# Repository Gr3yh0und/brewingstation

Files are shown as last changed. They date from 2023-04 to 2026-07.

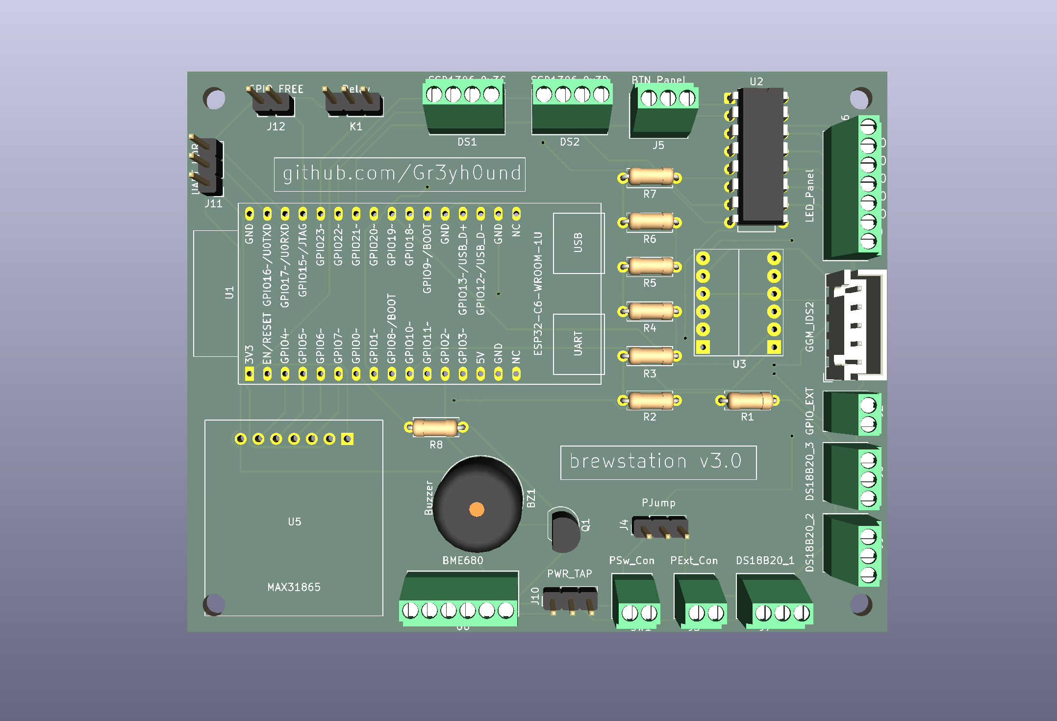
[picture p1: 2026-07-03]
brewingstation3/kicad/brewingstation3.png

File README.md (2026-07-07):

# Brewing Station






Firmware, hardware, and PCB design for a DIY automated beer brewing controller. An ESP32-based device reads mash temperature from multiple sensors, drives a [GGM IDS2 induction cooktop](https://www.ggmgastro.com/de-de-eur/induktionsherd-3-5-kw-1) through PID control, and integrates with [CraftBeerPi](https://web.craftbeerpi.com/) via MQTT.

This repo tracks the project's evolution across several hardware/firmware generations.

Credit: the GGM IDS2 induction cooktop's RS232/serial protocol — pulse timings, command frames, power levels, and error codes — was reverse-engineered by [InnuendoPi](https://github.com/InnuendoPi) in [MQTTDevice2](https://github.com/InnuendoPi/MQTTDevice2). Every generation in this repo builds on that work.

## Own projects (in order of development)

| Folder | Status | Board | Build system | Notes |
|---|---|---|---|---|
| [brewingstation](brewingstation/) | V1 | ESP32 (DOIT ESP32 DEVKIT V1) | Arduino IDE (`.ino`) or PlatformIO | One firmware, two hardware variants: [breadboard](brewingstation/hardware/breadboard/) and [fabricated PCB](brewingstation/hardware/pcb/). Documented in its own [README](brewingstation/README.md). |
| [brewingstation3](brewingstation3/) | **WIP** | ESP32-C6-WROOM-1U | PlatformIO | Full rewrite: PID mash control, multi-sensor support, safety shutdowns, brew timer, KiCad schematic, 3D-printable case. See [README](brewingstation3/README.md), [HARDWARE.md](brewingstation3/HARDWARE.md), [BOM.md](brewingstation3/BOM.md), [CASE.md](brewingstation3/CASE.md). |

`brewingstation` carries a `platformio.ini` (`src_dir = .`) alongside its `.ino`, so both PlatformIO and the Arduino IDE build from the same source file — pick whichever toolchain you prefer.

All generations share the same core idea: control the GGM IDS2 induction cooktop over its proprietary serial protocol, read temperature from DS18B20/PT100/PT1000/BME sensors, drive a couple of OLED displays and status LEDs, and talk to CraftBeerPi over MQTT.

`brewingstation3` is where active development happens; the earlier folders are kept as historical/reference hardware revisions. It is **work in progress**: firmware compiles but is not yet proven on real hardware — the PCB hasn't been soldered/assembled, nothing has been tested end-to-end, and the 3D-printable case hasn't been printed.

## Getting started

Each own-project folder is self-contained with its own README and config. In general:

1. Pick a generation — `brewingstation3` for new builds, the earlier folders for reference or repairing existing hardware.
2. Copy `config_example.h` (or `include/config_example.h` for `brewingstation3`) to `config.h` and fill in your MQTT/OTA settings (`brewingstation3` also provisions WiFi separately, via a WiFiManager captive portal on first boot — see its README). `config.h` is gitignored — never commit real credentials.
3. Build with PlatformIO (`pio run`) or open the `.ino` directly in the Arduino IDE — see that folder's README for board-specific notes.

The whole repo can also be opened as a single VS Code workspace via [brewingstation.code-workspace](brewingstation.code-workspace).

## Testing

`brewingstation3` has a native unit test suite for its hardware-independent logic (calibration math, button-ladder mapping, induction error codes) — runs on the host, no ESP32 toolchain or device required:

```sh
cd brewingstation3
pio test -e native
```

CI runs both the firmware build and this test suite on every push — see the badge above or [.github/workflows/build-brewingstation3.yml](.github/workflows/build-brewingstation3.yml).

## License

[MIT](LICENSE) — see [LICENSE](LICENSE) for the full text.

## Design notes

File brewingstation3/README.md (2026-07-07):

# Brewing Station 3

Automated beer brewing temperature controller. Reads temperature from multiple sensors, controls a GGM IDS2 induction cooker via a proprietary serial protocol, and runs a PID loop to hold a target mash temperature. Integrates with CraftBeerPi 3 and 4 via MQTT.

**Status: work in progress.** Firmware compiles but is not yet proven on real hardware — the PCB hasn't been soldered/assembled, nothing has been tested end-to-end, and the 3D-printable case hasn't been printed.

**Board:** ESP32-C6-WROOM-1U (ESP32-C6-DevKitC-1-N8)  
**Toolchain:** PlatformIO + VS Code (see [platformio.ini](platformio.ini))  
**Schematic:** KiCad 10 — see [kicad/](kicad/)

| Document | Contents |
|---|---|
| [HARDWARE.md](HARDWARE.md) | Sensors, actuators, connectors, pin map, IDS2 protocol, displays |
| [BOM.md](BOM.md) | Full bill of materials with order links |
| [CASE.md](CASE.md) | 3D-printable enclosure — dimensions, assembly, panel layout |

## Releases

Versioned as `3.0.0-alpha.N` (SemVer, pre-1.0 track) while the hardware is unverified — every [release](../../releases) is marked **pre-release** on GitHub until the PCB is built, soldered, and confirmed working end-to-end, at which point it graduates to `3.0.0`. Tags use a plain `3.*` pattern (no `v` prefix) to avoid colliding with `brewingstation` (V1)'s `vX.Y.Z` tags.

Cutting a release: `git tag 3.0.0-alpha.N && git push origin 3.0.0-alpha.N` — this runs the native test suite as a gate, then builds and publishes binaries, a KiCad design snapshot, and the case source to a GitHub Release. See [.github/workflows/release-brewingstation3.yml](../.github/workflows/release-brewingstation3.yml).

---

## Software Features

### Brewing Control
- **PID temperature control** — Proportional on Measurement (P_ON_M) mode. Default tuning: P=45.27, I=0.2371, D=7.2. All parameters adjustable at runtime via MQTT. Setpoint can be configured while PID is off.
- **Induction cooker control** — GGM IDS2 controlled via a proprietary 33-bit pulse-width serial protocol. 6 discrete power levels (P0–P5); intermediate percentages achieved by PWM-cycling between adjacent levels in a 20-second window. Relay stays on for 60 seconds after power-off for fan cooldown.
- **Multi-sensor support** — Up to 5 sensors total: DS18B20 (OneWire, auto-detected), PT100X via MAX31865, BME680. Sensors auto-detected at boot; bad DS18B20 readings (-127°C) are discarded and the previous value retained.
- **Power cap** — Configurable maximum induction output percentage (`INDUCTION_POWER_CAP`, default 100%). Applied to both the PID output path and direct `heater/power` MQTT commands. Adjustable at runtime via `induction/cap` MQTT topic without reflashing.
- **Brew timer** — Countdown timer driven via MQTT (`timer/set`, `timer/control`). Supports start, pause, and reset. Remaining time shown on Display 1 when active. Expiry logged via syslog.
- **Safety shutdowns** — Three automatic cutoffs disable induction power and the PID: (1) sensor staleness: primary sensor has not reported for 30 seconds; (2) thermal runaway: temperature exceeds setpoint by more than 5°C; (3) cooker error codes: E3 overheat, E7 low voltage, or E8 high voltage received from the cooker RX line. All events are logged via syslog at CRIT severity.

### User Interface
- **Dual OLED display** — Display 1: runtime/clock/timer, PID target temperature, PID output %, Wi-Fi/MQTT status icons. Display 2: sensor temperatures, induction power level and percentage, fan indicator, PID active flag.
- **Button control** — 6 panel buttons on a single ADC pin (IO1) via resistor ladder. Each button directly sets the GGM IDS2 induction cooker to a fixed power level (0 / 20 / 40 / 60 / 80 / 100%). Debounced (250 ms). See button mapping table below.
- **Power-level LEDs** — 8 LEDs driven via PCF8574 I2C GPIO expander (address 0x20), active-LOW. The lit LED always reflects the current IDS2 power state: whichever power level is active, the corresponding LED turns on. The LED updates whenever the power level changes — whether set by a button press, MQTT command, or PID output. P6/P7 are spare outputs available for custom use.

### Network & Platform
- **CraftBeerPi 3 & 4** compatible via MQTT.
- **WiFi provisioning via captive portal** — WiFiManager opens an AP automatically on first boot or a failed connect, or can be forced by holding any panel button for ~2s at power-on. No WiFi credentials are stored in `config.h`. The same portal also lets you set the MQTT broker address, MQTT topic prefix, and OTA password without reflashing.
- **OTA firmware updates** — ArduinoOTA on port 8266, or via the web dashboard's upload form (`http://<ip>/update`); both password-protected (`OTA_PASSWORD` in `config.h`, changeable later via the WiFiManager portal).
- **Web dashboard** — three tabbed pages at `http://<ip>/`, with the hostname and running firmware version shown in the nav bar: **Status** (sensors, setpoint, PID/mode, induction power, relay/GPIO5, brew timer, WiFi signal, uptime, version — auto-refreshes every 5s, no login), **Update** (browser firmware upload, a link to the GitHub releases page, and a "Check for update" button that compares the running version against GitHub directly from the browser), and **Config** (current MQTT/WiFi/PID settings, with a JSON download for backup). Update and Config require the OTA password (HTTP Basic Auth).
- **mDNS** — Device advertises as `ESP-BREWING.local`.
- **Syslog** — UDP logging to backend server on port 514.
- **NTP time sync** — `configTzTime()` called after WiFi connects; POSIX timezone string configurable via `NTP_TIMEZONE` in `config.h`. When synced, Display 1 shows wall-clock time instead of uptime.
- **Hardware watchdog** — ESP32 task watchdog timer (`WDT_TIMEOUT_S`, default 30 s). Reboots the device if `loop()` stalls for any reason.

### Button Mapping

Each button sets the GGM IDS2 induction cooker to a fixed power level. The matching power-level LED lights up immediately after the button is pressed. See [HARDWARE.md](HARDWARE.md#button--led-panel-external--not-on-pcb) for wiring details.

| Button | Panel ref | ADC range | IDS2 power | LED |
|---|---|---|---|---|
| B1 | SW2 | 3200–3299 | 0% (off) | LD1 (LED_0) |
| B2 | SW3 | 3000–3199 | 20% | LD2 (LED_20) |
| B3 | SW4 | 2600–2999 | 40% | LD3 (LED_40) |
| B4 | SW5 | 2000–2599 | 60% | LD4 (LED_60) |
| B5 | SW6 | 1–1999 | 80% | LD5 (LED_80) |
| B6 | SW7 | 0 (ADC_BTN shorted to GND) | 100% | LD6 (LED_100) |

> The LEDs also update when the power level is changed via MQTT or PID output — the lit LED always reflects the **current** IDS2 state, not just the last button pressed.

---

## MQTT

All topics are built from `MQTT_ROOT_PATH / MQTT_DEVICE` — set in `config.h` as first-boot defaults, changeable afterward via the WiFiManager portal (persisted to `/netconfig.json`).

| Topic | Direction | Payload fields |
|---|---|---|
| `.../sensor/N` | publish | `temp` (°C), `ts` |
| `.../induction` | publish | `relay`, `active`, `power`, `level`, `error`, `cap`, `ts` |
| `.../induction/set` | subscribe | `power` (0–100); `state "off"` cuts power |
| `.../induction/cap` | subscribe | `cap` (0–100) — runtime power ceiling |
| `.../pid` | publish | `enabled`, `mode`, `setpoint`, `input`, `output`, `diff`, `P`, `I`, `D`, `ts` |
| `.../pid/enable` | subscribe | `enabled` (bool) |
| `.../pid/reset` | subscribe | _(any payload)_ — resets PID output to 0 |
| `.../pid/p` | subscribe | `P` (float) |
| `.../pid/i` | subscribe | `I` (float) |
| `.../pid/d` | subscribe | `D` (float) |
| `.../pid/setpoint` | subscribe | `setpoint` (float, 0–100°C) |
| `.../timer` | publish | `running`, `paused`, `remaining` (s), `duration` (s), `ts` |
| `.../timer/set` | subscribe | `duration` (seconds) |
| `.../timer/ctl` | subscribe | `cmd`: `"start"` / `"pause"` / `"reset"` |
| `.../device` | publish | `uptime`, `heap`, `rssi`, `version`, `mode`, `ts` |
| `.../device/mode` | subscribe | `mode`: `"standalone"` / `"slave"` |
| `.../relay` | publish | `state`, `remaining`, `ts` |
| `.../relay/set` | subscribe | `state`: `"on"` / `"off"`; optional `duration` (s) |
| `.../gpio_ext` | publish | `state`, `remaining`, `ts` |
| `.../gpio_ext/set` | subscribe | `state`: `"on"` / `"off"`; optional `duration` (s) |

---

## Configuration

Copy `include/config_example.h` to `include/config.h` and fill in your values. `config.h` is gitignored.

```cpp
#define HOSTNAME        "ESP-BREWING"
#define SERVER_ADDRESS  "192.168.0.x"   // Raspberry Pi IP
#define MQTT_ROOT_PATH  "home"
#define MQTT_DEVICE     "brewery"
```

**WiFi credentials are not set in `config.h`.** On first boot (or whenever no saved WiFi credentials connect), the device opens a WiFiManager captive-portal AP — connect to it from a phone/laptop and submit your WiFi SSID/password, MQTT broker address, MQTT topic prefix, and OTA password through its web form. These are stored in the ESP32's NVS (WiFi) and `/netconfig.json` (the rest), surviving reboots and reflashes. To reprovision later without clearing flash, hold any panel button for ~2s at power-on to force the portal open again.

**PT100X vs PT1000:** Default is PT1000 (`R_NOM=1000`, `R_REF=4300`). Change both to `100` / `430` for PT100.

**PID tuning:** Default values (`P=45.27`, `I=0.2371`, `D=7.2`) are tuned for a specific vessel. Adjust `PID_DEFAULT_P/I/D` in `config.h`. Values can also be changed at runtime via MQTT.

**Button ADC thresholds:** `BUTTON_THRESHOLD_B1–B5` depend on actual resistor values. Measure with serial monitor and adjust if buttons trigger at the wrong levels.

**Safety thresholds:** `PID_SAFETY_OVERSHOOT` (default 5°C) and `SENSOR_STALE_TIMEOUT_MS` (default 30s).

**Power cap:** `INDUCTION_POWER_CAP` (default 100%). Override at runtime via `induction/cap` MQTT.

**Watchdog:** `WDT_TIMEOUT_S` (default 30 s).

**NTP:** `NTP_SERVER` (default `pool.ntp.org`) and `NTP_TIMEZONE` (POSIX string). See [nayarsystems/posix_tz_db](https://github.com/nayarsystems/posix_tz_db).

---

## Build & Flash (PlatformIO)

```sh
# Build
pio run -e esp32c6

# Upload via USB-CDC (no external USB-UART chip needed)
pio run -e esp32c6 -t upload

# Serial monitor
pio device monitor

# Debug build (verbose ESP-IDF logs)
pio run -e esp32c6_debug
```

Or use the PlatformIO sidebar in VS Code (Build ✓ / Upload → / Monitor icons).

---

## Libraries

All dependencies are managed by PlatformIO via `platformio.ini`.

| Library | Author | Constraint | Installed |
|---|---|---|---|
| PubSubClient | Nick O'Leary | `^2.8` | 2.8 |
| ArduinoJson | Benoit Blanchon | `^7.0` | 7.4.3 |
| Syslog | Martin Sloup (arcao) | `^2.0` | 2.0.0 |
| Arduino-PID-Library | Brett Beauregard | `^1.2` | 1.2.1 |
| OneWire | Paul Stoffregen | local `lib/` | 2.3.8 (patched) |
| DallasTemperature | Miles Burton | `^3.9` | 3.11.0 |
| Adafruit Unified Sensor | Adafruit | `^1.1` | 1.1.15 |
| Adafruit MAX31865 | Adafruit | `^1.1` | 1.6.2 |
| Adafruit BME680 | Adafruit | `^2.2` | 2.3.0 |
| Adafruit GFX | Adafruit | `^1.11` | 1.12.6 |
| Adafruit SSD1306 | Adafruit | `^2.5` | 2.5.16 |
| PCF8574 | Rob Tillaart | `^0.3` | 0.3.9 |
| arduino-timer | contrem | unpinned | 3.0.1 |

**OneWire note:** Kept as a local copy in `lib/OneWire/` because the upstream release does not handle the ESP32-C6 GPIO register struct (typed fields requiring `.val` in arduino-esp32 3.x). The patch adds `|| CONFIG_IDF_TARGET_ESP32C6` to each `#if CONFIG_IDF_TARGET_ESP32C3` guard in `util/OneWire_direct_gpio.h`.

**Platform:** pioarduino community fork (`pioarduino/platform-espressif32 @ stable`). The official `espressif32` platform references a RISC-V toolchain package (`toolchain-riscv32-esp @ 13.2.0+20240530`) that was removed from the PlatformIO registry; the pioarduino fork bundles the toolchain directly. Bundles arduino-esp32 3.x, which is required for ESP32-C6 support.

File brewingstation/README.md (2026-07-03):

# Brewing Station (V1)

Automated beer brewing temperature controller. Reads temperature from multiple sensors, controls a GGM IDS2 induction cooker via a proprietary serial protocol, and runs a PID loop to hold a target mash temperature. Integrates with CraftBeerPi 3 and 4 via MQTT.

The idea: a "remote hands" station for CraftBeerPi with a local interface, so it also works standalone without a Pi — e.g. for manual-temperature-control outdoor cooking.

**MCU:** ESP32 (DOIT ESP32 DEVKIT V1)
**Toolchain:** Arduino IDE or PlatformIO (see [platformio.ini](platformio.ini))
**Hardware variants:** one firmware, two builds — [breadboard prototype](hardware/breadboard/) and a [fabricated 2-layer PCB](hardware/pcb/) (see [Hardware Variants](#hardware-variants) below)
**Successor:** [brewingstation3](../brewingstation3) — full rewrite on ESP32-C6 with safety shutdowns, brew timer, and a printable case

---

## Induction Cooker

Within this project the [GGM Gastro IDS2 induction cooker](https://www.ggmgastro.com/de-de-eur/induktionsherd-3-5-kw-1) is used to heat the mash tun. It has an external control panel connected via a serial line — reverse-engineered by [InnuendoPi](https://github.com/InnuendoPi) in [MQTTDevice2](https://github.com/InnuendoPi/MQTTDevice2), which this project builds on.

Tested with both CraftBeerPi 3 and 4 — the MQTT API is identical between the two.

---

## Hardware

| Component | Interface | Purpose |
|---|---|---|
| DS18B20 (×2–3) | OneWire | Mash temperature — breadboard build uses 2, PCB build's schematic shows 3 |
| MAX31865 (PT1000) | Software SPI | High-accuracy RTD temperature |
| BME280 | Software SPI | Ambient temperature / humidity / pressure |
| GGM IDS2 induction cooker | 3-wire serial | Heat source |
| 2× SSD1306 OLED 128×64 | I2C, different addresses | Temperature + status display |
| Buttons + LEDs | GPIO | Manual power control (aluminium switches with integrated LEDs) |

The firmware detects sensors at runtime and adapts — the same sketch runs unmodified on either hardware variant, as long as `config.h` pin assignments match the board you're using.

---

## Hardware Variants

Both variants run the exact same firmware (`brewingstation.ino`) — the only difference is the physical build.

| Aspect | Breadboard | PCB |
|---|---|---|
| Form factor | Breadboard prototype | Custom fabricated 2-layer PCB |
| Level shifter | Not shown | Present (3.3V ↔ 5V) |
| DS18B20 count | 2 (config default) | 3 (shown in schematic) |
| Expansion connectors | None | PPump, PJump, PExt, GPIOs |
| Design files | [hardware/breadboard/](hardware/breadboard/) | [hardware/pcb/](hardware/pcb/) |

### Breadboard design files

| File | Description |
|---|---|
| `brewingstation.fzz` | Fritzing project |
| `brewingstation_breadboard.png` | Breadboard wiring view |
| `brewingstation_schematics.png` | Schematic / circuit diagram |
| `brewingstation_pcb.png` | PCB layout (Fritzing-generated) |
| `gerber_pcb.zip` | Gerber files for PCB fabrication |

### PCB design files

| File | Description |
|---|---|
| `brewingstation2.fzz` | Fritzing project (original) |
| `brewingstation2_updated.fzz` | Fritzing project (revised PCB layout) |
| `brewingstation2_Steckplatine.png` | Breadboard wiring view |
| `brewingstation2_Schaltplan.png` | Schematic / circuit diagram |
| `brewingstation2_Leiterplatte.png` | PCB layout (2-layer, "BREWSTATION" silkscreen) |
| `gerber.zip` | Gerber files for PCB fabrication |

The `_updated.fzz` reflects at least one PCB revision after initial design — use the gerbers from the latest revision for fabrication.

### Notable: Level Shifter (PCB variant)

The PCB schematic includes a logic level converter (3.3V ↔ 5V), bridging the ESP32's 3.3V GPIO levels to the 5V signalling required by the induction cooker serial line and/or relay module.

---

## MQTT

Topics are built from `MQTT_ROOT_PATH / MQTT_DEVICE` (set in `config.h`).

| Topic | Direction | Payload fields |
|---|---|---|
| `.../temperature/N` | publish | `temperature` (°C) |
| `.../heater` | publish | `relayOn`, `inductionOn`, `powerPercent`, `powerLevel` |
| `.../heater/power` | subscribe | `state` (`"off"` or unset), `power` (0–100) |
| `.../pid` | publish | `state`, `P`, `I`, `D`, `input`, `targetTemperature`, `tempDiff`, `output` |
| `.../pid/#` | subscribe | PID tuning/setpoint commands |

---

## Configuration

Copy `config_example.h` to `config.h` and fill in your network credentials and server address. `config.h` is gitignored — never commit real credentials.

```cpp
#define HOSTNAME        "ESP-BREWING"
#define SSID_NAME       "your-ssid"
#define SSID_PASSWORD   "your-password"
#define SERVER_ADDRESS  "192.168.0.x"
#define MQTT_ROOT_PATH  "root"
#define MQTT_DEVICE     "brewery"
```

---

## Build & Flash

**PlatformIO:**

```sh
pio run -e esp32doit-devkit-v1
pio run -e esp32doit-devkit-v1 -t upload
pio device monitor
```

**Arduino IDE:** open `brewingstation.ino` directly and install the libraries listed at the top of the sketch.

---

## Known Gaps

This is the earliest surviving generation of the project — some functionality is missing or incomplete:

- PID integration (present in code, not fully tuned/validated)
- Sensor handling (no runtime detection/calibration — see [brewingstation3](../brewingstation3) for that)
- Humidity and pressure MQTT topics (BME280 reads them, but only temperature is published)
- Brew timers / mash-step display (also needs CraftBeerPi-side adaptations)

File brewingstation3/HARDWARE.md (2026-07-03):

# Brewing Station 3 — Hardware Reference

**MCU:** ESP32-C6-WROOM-1U on ESP32-C6-DevKitC-1-N8  
RISC-V single-core 160 MHz, WiFi 6, BLE 5.3, 3.3V I/O, USB-CDC built-in.

---

## Sensors

| Sensor | Interface | Purpose |
|---|---|---|
| DS18B20 (×3) | OneWire (IO11) | Mash temperature — sensor 0 is the PID input |
| MAX31865 / PT100X | Software SPI (CS: IO4) | High-accuracy RTD temperature |
| BME680 | Software SPI (CS: IO2) | Ambient temperature / humidity / pressure |

MAX31865 and BME680 share the same MOSI/MISO/CLK bus (IO7/IO6/IO5) with separate CS pins.

---

## Actuators & UI

| Component | Interface | Purpose |
|---|---|---|
| GGM IDS2 induction cooker | 3-wire serial via BSS138 level shifter (IO18/IO19/IO20) | Heat source |
| Relay module (K1) | IO21 (direct 3.3V, no level shifter) | General-purpose relay (pump / Rührwerk) — external module via 3-pin Dupont header |
| Magnetic buzzer SUMMER CPM 121 (BZ1) | IO0 → BC547B NPN → buzzer → +3V3 | Audible alerts (step complete, safety events) |
| PCF8574 I2C GPIO expander | I2C 0x20 (IO23/IO22) | Drives 8 power-level LEDs (active-LOW) |
| 6× LEDs (LD1–LD6) via P0–P5 | PCF8574 + R2–R7 (330Ω) → J15–J20 (pin 3) | IDS2 power state indicator — lit LED = current power level (0/20/40/60/80/100%) |
| 2× spare LEDs (LD7–LD8) via P6–P7 | PCF8574 + R15–R16 (330Ω) → J21, J22 (pin 2) | Spare outputs for custom use |
| 6× buttons (SW2–SW7) | Resistor ladder (IO1 / ADC1) → J15–J20 (pin 2) | Sets IDS2 cooker power level directly (0/20/40/60/80/100%) |
| 2× SSD1306 OLED 128×64 | I2C 0x3C / 0x3D (IO23/IO22) | Temperature + status display |

---

## Level Shifter

BSS138 4-channel bidirectional level shifter module (VCCA=3.3V, VCCB=5V) bridges the ESP32-C6's 3.3V GPIO to the 5V signalling required by the induction cooker (WHITE/YELLOW/BLUE) on CH2–CH4. CH1 is not connected (IO10 is broken out directly via J13). The relay module is driven directly at 3.3V — select a relay module with 3.3V-compatible opto-coupler input.

---

## Power Chain

IDS2 VCC tap or PExt → PJump (source select) → PSw (on/off) → +5V rail → DevKit VIN + relay module + BSS138 VCCB

---

## PCB Connectors

**Female sockets (2.54mm) — module plugs in:**

| Ref | Component | Socket |
|---|---|---|
| U1 | ESP32-C6-DevKitC-1 | 2× 1×16 female socket strip — DevKit is swappable |
| U3 | BSS138 level shifter module | 2×6 female, 2.54mm |
| U5 | MAX31865 module | 1×7 female, 2.54mm |

**External module connector (Dupont cables):**

| Ref | Component | Connector |
|---|---|---|
| K1 | Relay module | 1×3 male header, 2.54mm (VCC / GND / IN) — relay load contacts on module's own screw terminals |

**Male headers (2.54mm) — jumper cap or dupont wires plug in:**

| Ref | Purpose | Pins |
|---|---|---|
| J4 | PSource — power source selector | 3 (IDS2 tap / PSOURCE_OUT / PExt); short 1-2 or 2-3 |
| J10 | PWR_TAP — voltage reference | 3 (GND, +3V3, +5V) |
| J11 | UART — IO16 TX / IO17 RX | 3 (GND, TX, RX) |

**Phoenix screw terminal GPIO breakouts:**

| Ref | Purpose | Pins |
|---|---|---|
| J12 | GPIO15 breakout | 2 (GND, GPIO15) |
| J13 | GPIO10 breakout | 2 (GND, GPIO10) |
| J14 | GPIO3_ADC breakout | 2 (GND, GPIO3_ADC) |

**IDS2 connector (internal):**

| Ref | Purpose | Type |
|---|---|---|
| J1 | GGM IDS2 induction cooker | Phoenix MPT 5-pin, 2.54mm — IDS2 cable feeds through case wall, individual wires screwed in (IDS2_5V / GND / WHITE / YELLOW / BLUE) |

---

## External Wiring — Screw Terminal Connectors

All screw terminal connections use **Phoenix Contact MPT 0,5/X-2,54** PCB terminal blocks (2.54mm pitch, screw clamp, 6A / 160V, green).  
Reichelt article numbers: [**PHC 1725656**](https://www.reichelt.de/de/de/shop/produkt/leiterplattenklemme_2-polig_rm_2_54-60874) (2-pin), [**PHC 1725669**](https://www.reichelt.de/de/de/shop/produkt/leiterplattenklemme_3-polig_rm_2_54_mm-60875) (3-pin), [**PHC 1725672**](https://www.reichelt.de/de/de/shop/produkt/leiterplattenklemme_4-polig_rm_2_54_mm-60876) (4-pin), [**PHC 1725685**](https://www.reichelt.de/de/de/shop/produkt/leiterplattenklemme_5-polig_rm_2_54_mm-255909) (5-pin).

| Ref | Connector | Pins | Wires to |
|---|---|---|---|
| J3 | External 5V power input (PExt) | 2 (+5V, GND) | Power supply / USB charger |
| SW1 | Main power switch + integrated LED | 4 (SW_A, SW_B, LED+, LED−) | Panel-mounted metal switch; LED driven via R17 (470Ω) from PSOURCE_OUT — always on when power is present |
| J15–J20 | Button + LED per power level (0/20/40/60/80/100%) | 3 (GND, BTN, LED) | J15=0%, J16=20%, J17=40%, J18=60%, J19=80%, J20=100% — each carries one panel button (SW2–SW7) and its matching LED (LD1–LD6) |
| J21, J22 | Spare LEDs (LED_P6, LED_P7) | 2 (GND, LED) | PCF8574 P6/P7 spare outputs |
| J7 | DS18B20 sensor 1 | 3 (GND, +3V3, DQ) | Wire to case-mounted connector → probe |
| J8 | DS18B20 sensor 2 | 3 (GND, +3V3, DQ) | Wire to case-mounted connector → probe |
| J9 | DS18B20 sensor 3 | 3 (GND, +3V3, DQ) | Wire to case-mounted connector → probe |
| U5 | PT1000/PT100 probe (MAX31865) | 4 (FORCE+, FORCE−, RTDIN+, RTDIN−) | Internal cable → case connector → RTD probe |
| U6 | BME680 module | 6 (VCC, GND, SCK, SDI, SDO, CSB) | Module wired directly into terminal |
| DS1 | SSD1306 OLED 0x3C | 4 (GND, VCC, SCL, SDA) | OLED module wired directly into terminal |
| DS2 | SSD1306 OLED 0x3D | 4 (GND, VCC, SCL, SDA) | OLED module wired directly into terminal |
| J12 | GPIO15 breakout | 2 (GND, GPIO15) | Spare GPIO, ADC-capable |
| J13 | GPIO10 breakout | 2 (GND, GPIO10) | Spare GPIO, ADC-capable |
| J14 | GPIO3_ADC breakout | 2 (GND, GPIO3_ADC) | Spare ADC input (ADC1_CH3) |

---

## Pin Map

DevKit pad numbers from the `PCM_Espressif:ESP32-C6-DevKitC-1` footprint.  
IO8/IO9 are strapping pins (DevKit BOOT button) — do not drive as outputs.  
IO12/IO13 are USB D−/D+ — occupied by USB-CDC, not available.  
IO14 is not exposed on the DevKitC-1 headers.  
IO16/IO17 are UART0 TX/RX — free because USB-CDC replaces the hardware UART for `Serial`.

| GPIO | DevKit pad | Signal | Status | Notes |
|---|---|---|---|---|
| IO0 | 7 | Buzzer (BUZZER_PIN) | **Used** | PWM via LEDC → BC547B NPN (Q1) → BZ1 piezo |
| IO1 | 8 | Button ladder (ADC_BTN) | **Used** | ADC1_CH1; 6-button resistor ladder |
| IO2 | 12 | BME680 SPI CS | **Used** | Software SPI chip-select |
| IO3 | 13 | GPIO3_ADC (J14) | **Broken out** | ADC1_CH3; 2-pin Phoenix screw terminal (GND + GPIO3_ADC) |
| IO4 | 3 | MAX31865 SPI CS | **Used** | Software SPI chip-select |
| IO5 | 4 | SPI CLK | **Used** | Shared bus: MAX31865 + BME680 |
| IO6 | 5 | SPI MISO (DO) | **Used** | Shared bus: MAX31865 + BME680 |
| IO7 | 6 | SPI MOSI (DI) | **Used** | Shared bus: MAX31865 + BME680 |
| IO8 | 9 | — | **Restricted** | BOOT strapping pin — do not drive as output |
| IO9 | 22 | — | **Restricted** | BOOT strapping pin — do not drive as output |
| IO10 | 10 | GPIO10 (J13) | **Broken out** | ADC1_CH2; 2-pin Phoenix screw terminal (GND + GPIO10); BSS138 CH1 nc |
| IO11 | 11 | DS18B20 OneWire bus (SENSOR_BUS_PIN) | **Used** | 4.7kΩ pull-up to 3V3 on PCB |
| IO12 | 19 | — | **Restricted** | USB D− — occupied by USB-CDC |
| IO13 | 20 | — | **Restricted** | USB D+ — occupied by USB-CDC |
| IO14 | — | — | **Not exposed** | Not on DevKitC-1 headers |
| IO15 | 29 | GPIO15 (J12) | **Broken out** | 2-pin Phoenix screw terminal (GND + GPIO15) |
| IO16 | 31 | UART_HDR TX | **Free** | UART0 TX; broken out on J11; usable as GPIO when using USB-CDC |
| IO17 | 30 | UART_HDR RX | **Free** | UART0 RX; broken out on J11; usable as GPIO when using USB-CDC |
| IO18 | 23 | Induction WHITE (relay enable) | **Used** | via BSS138 level shifter |
| IO19 | 24 | Induction YELLOW (TX) | **Used** | via BSS138 level shifter |
| IO20 | 25 | Induction BLUE (RX interrupt) | **Used** | via BSS138 level shifter |
| IO21 | 26 | Relay module control (RELAY_PIN) | **Used** | direct 3.3V to K1 Dupont header |
| IO22 | 27 | I2C SCL | **Used** | Displays (0x3C, 0x3D) + PCF8574 (0x20) |
| IO23 | 28 | I2C SDA | **Used** | Displays (0x3C, 0x3D) + PCF8574 (0x20) |

**Summary: 14 used · 4 restricted · 1 not exposed · 3 broken out (IO10→J13, IO15→J12, IO3→J14) · 2 free (IO16/IO17 on J11 UART header)**

### PCF8574 I2C GPIO expander (address 0x20)

| Pin | Signal | Notes |
|---|---|---|
| P0 | LED 0% (off) | Active-LOW |
| P1 | LED 20% | Active-LOW |
| P2 | LED 40% | Active-LOW |
| P3 | LED 60% | Active-LOW |
| P4 | LED 80% | Active-LOW |
| P5 | LED 100% | Active-LOW |
| P6 | LED_P6 spare | Active-LOW; via R15 (330Ω) to J21 pin 2 |
| P7 | LED_P7 spare | Active-LOW; via R16 (330Ω) to J22 pin 2 |

---

## Induction Cooker

**Model:** GGM IDS2

### Wiring
| Wire | GPIO | Role |
|---|---|---|
| WHITE | IO18 | Relay — switches mains power to the cooker |
| YELLOW | IO19 | TX — sends power level commands |
| BLUE | IO20 | RX — receives status/feedback (interrupt) |

All three signals pass through the BSS138 4-channel level shifter (3.3V → 5V).

### Serial Protocol
The cooker uses a proprietary pulse-width serial protocol. Each command is a 33-bit frame preceded by a start pulse.

| Signal | Duration |
|---|---|
| Start pulse (HIGH) | 25 ms |
| Gap (LOW) | 10 ms |
| Bit HIGH | 5120 µs |
| Bit LOW | 1280 µs |
| Bit separator (LOW) | 1280 µs |

Protocol documented at [InnuendoPi/MQTTDevice2](https://github.com/InnuendoPi/MQTTDevice2).

### Power Levels
| Level | Command | Power |
|---|---|---|
| P0 | `101000000000000000000000001000000` | 0% (off) |
| P1 | `100100000100000000000000010100000` | 20% |
| P2 | `100100000010000000000000001100000` | 40% |
| P3 | `100100000110000000000000011100000` | 60% |
| P4 | `100100000001000000000000000010000` | 80% |
| P5 | `100100000101000000000000100100000` | 100% |

### Intermediate Power (PWM Cycling)
Percentages between discrete levels are achieved by time-multiplexing two adjacent levels within a 20-second window.

**Example — 30%** (between P1=20% and P2=40%):
- 10 s at P1 (20%) + 10 s at P2 (40%) = effective 30%

### Status & Error Codes
| Code | Error | Trigger safety shutdown |
|---|---|---|
| 0 | OK — no fault | — |
| 1, 2 | E0 — no pot detected | — |
| 3 | E1 — circuit fault | — |
| 4, 5 | E3 — cooker overheat | yes |
| 6 | E4 — temperature sensor fault | — |
| 9 | E7 — supply voltage low | yes |
| 10 | E8 — supply voltage high | yes |
| 14 | EC — control panel fault | — |

### Relay & Fan Cooldown
WHITE relay controls cooker mains power. Stays on for **60 seconds after power-off** for fan cooldown. Configurable via `INDUCTION_FAN_DELAY` in `config.h`.

---

## Displays

Both displays are 128×64 SSD1306 OLEDs on I2C (0x3C and 0x3D). They refresh every 500ms.

### Display 1 — Status (0x3C)

Font: FreeSans9pt7b. Three rows separated by horizontal lines. Right strip (26px) carries status icons.

```
┌──────────────────────────────┬────────┐
│ Run   │ 012:34               │ [WiFi] │
├───────┴──────────────────────┤        │
│ Tgt   │ 67.5                 │  [●]   │
├──────────────────────────────┤        │
│ Out   │ 82%                  │ [MQTT] │
└──────────────────────────────┴────────┘
 ←─────────── 102px ──────────→ ← 26px→
```

**Row 1 content** (priority order):
| Priority | Label | Value | Condition |
|---|---|---|---|
| 1 | `Tmr` | `MM:SS` remaining | Brew timer running or paused |
| 2 | `Clk` | `HH:MM` | NTP time synced |
| 3 | `Run` | `MMM:SS` uptime | Fallback |

**Right status strip:**
| Position | Icon | Condition |
|---|---|---|
| Top | WiFi icon (24×24) | Always shown when Wi-Fi connected |
| Middle | Filled circle (heartbeat) | Toggles every 500ms |
| Bottom | `ERR` + code | Shown when a cooker error code is active |
| Bottom | MQTT envelope icon | Flashes briefly when an MQTT command is received |

### Display 2 — Temperatures & Power (0x3D)

Font: FreeSans18pt7b. Cross-divided into four quadrants.

```
┌──────────────────┬───────────────────┐
│                  │ PID  [fan]     3  │
│      23.5        │                   │
├──────────────────┼───────────────────┤
│                  │                   │
│      22.1        │        75         │
└──────────────────┴───────────────────┘
```

| Quadrant | Content |
|---|---|
| Top-left | `temperatures[0]` — primary mash sensor / PID input |
| Bottom-left | `temperatures[1]` — secondary sensor |
| Top-right | Power level `0`–`5`; replaced by error string when fault active |
| Bottom-right | Power `%` `0`–`100` |

---

## Button + LED Panel (external — not on PCB)

Each of J15–J20 carries one panel push-button (SW2–SW7) and its matching power-level LED (LD1–LD6) on a single 3-pin connector. For power level mapping and ADC thresholds see the [Button Mapping](README.md#button-mapping) table.

**J15–J20 pinout (3-pin Phoenix each):**

| Connector | Pin 1 | Pin 2 | Pin 3 | Panel refs |
|---|---|---|---|---|
| J15 | GND | BTN1 | LED_0 | SW2 + LD1 |
| J16 | GND | BTN2 | LED_20 | SW3 + LD2 |
| J17 | GND | BTN3 | LED_40 | SW4 + LD3 |
| J18 | GND | BTN4 | LED_60 | SW5 + LD4 |
| J19 | GND | BTN5 | LED_80 | SW6 + LD5 |
| J20 | GND | ADC_BTN | LED_100 | SW7 + LD6 |

> Pin 2 (BTN) wires to the switch; when pressed, switch shorts BTN to GND via pin 1.  
> Pin 3 (LED) wires to the LED anode; cathode returns to GND independently.

**J21, J22 pinout (2-pin Phoenix each):**

| Connector | Pin 1 | Pin 2 | Purpose |
|---|---|---|---|
| J21 | GND | LED_P6 | Spare LED output (PCF8574 P6) |
| J22 | GND | LED_P7 | Spare LED output (PCF8574 P7) |

> **Calibration note:** After assembly, press each button and print the raw `analogRead(BUTTON_ADC_PIN)` value over Serial. Adjust `BUTTON_THRESHOLD_Bx` in `config.h` to match actual readings if they differ from expected values.

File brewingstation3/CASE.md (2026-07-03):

# Brewing Station 3 — Case

A 3D-printable enclosure is provided in [`case/brewingstation3_case.scad`](case/brewingstation3_case.scad) (OpenSCAD).

---

## Design

Two-part box — print each part separately, no supports needed:

| Part | Print orientation | Key features |
|---|---|---|
| **Tray** (bottom + walls) | Upright, open top up | 4× screw bosses with M3 heat-set insert holes; 4× PCB standoffs (12 mm) |
| **Lid** (top plate) | Face up, flat | 2× OLED windows (26 × 14 mm); 4× M3 countersunk screw holes |

---

## Dimensions

| Property | Value |
|---|---|
| Outer footprint | 126 × 106 mm |
| Total height (assembled) | 90 mm |
| Internal cavity | 120 × 100 × 84 mm |
| Clearance around PCB | 10 mm each side |
| PCB height above floor | 15 mm (3 mm floor + 12 mm standoffs) |
| Wire space below PCB | 12 mm |
| Wire space above PCB | ~70 mm |

---

## Fasteners

| Item | Spec | Qty |
|---|---|---|
| Lid screws | M3 × 10 mm flat-head (countersunk) | 4 |
| Heat-set inserts | M3 × 4 mm brass knurl inserts | 4 |

Press inserts into the tray bosses with a soldering iron. Screws pass through the countersunk lid holes and thread into the inserts.

---

## Panel Cutouts

All side and lid holes (USB, connectors, buttons, sensors) are drilled by the user after printing. Pre-modelled openings:
- 2× rectangular OLED windows on the lid (positions adjustable via `oled1_cx` / `oled2_cx` in the `.scad` file)

---

## Recommended Panel Layout

| Face | Contents |
|---|---|
| **Top (lid)** | 2× OLED displays, 6× metal pushbuttons with LED rings (Ø16 mm hole each) |
| **Right side** | 3× DS18B20 connectors (J7/J8/J9), IDS2 cable (J1), button+LED panel (J15–J20), spare LEDs (J21/J22) |
| **Back** | Power switch (SW1), PExt power input (J3), USB-C (ESP32 DevKit) |
| **Left / front** | Optional: UART header (J11), GPIO breakouts (J12–J14) |

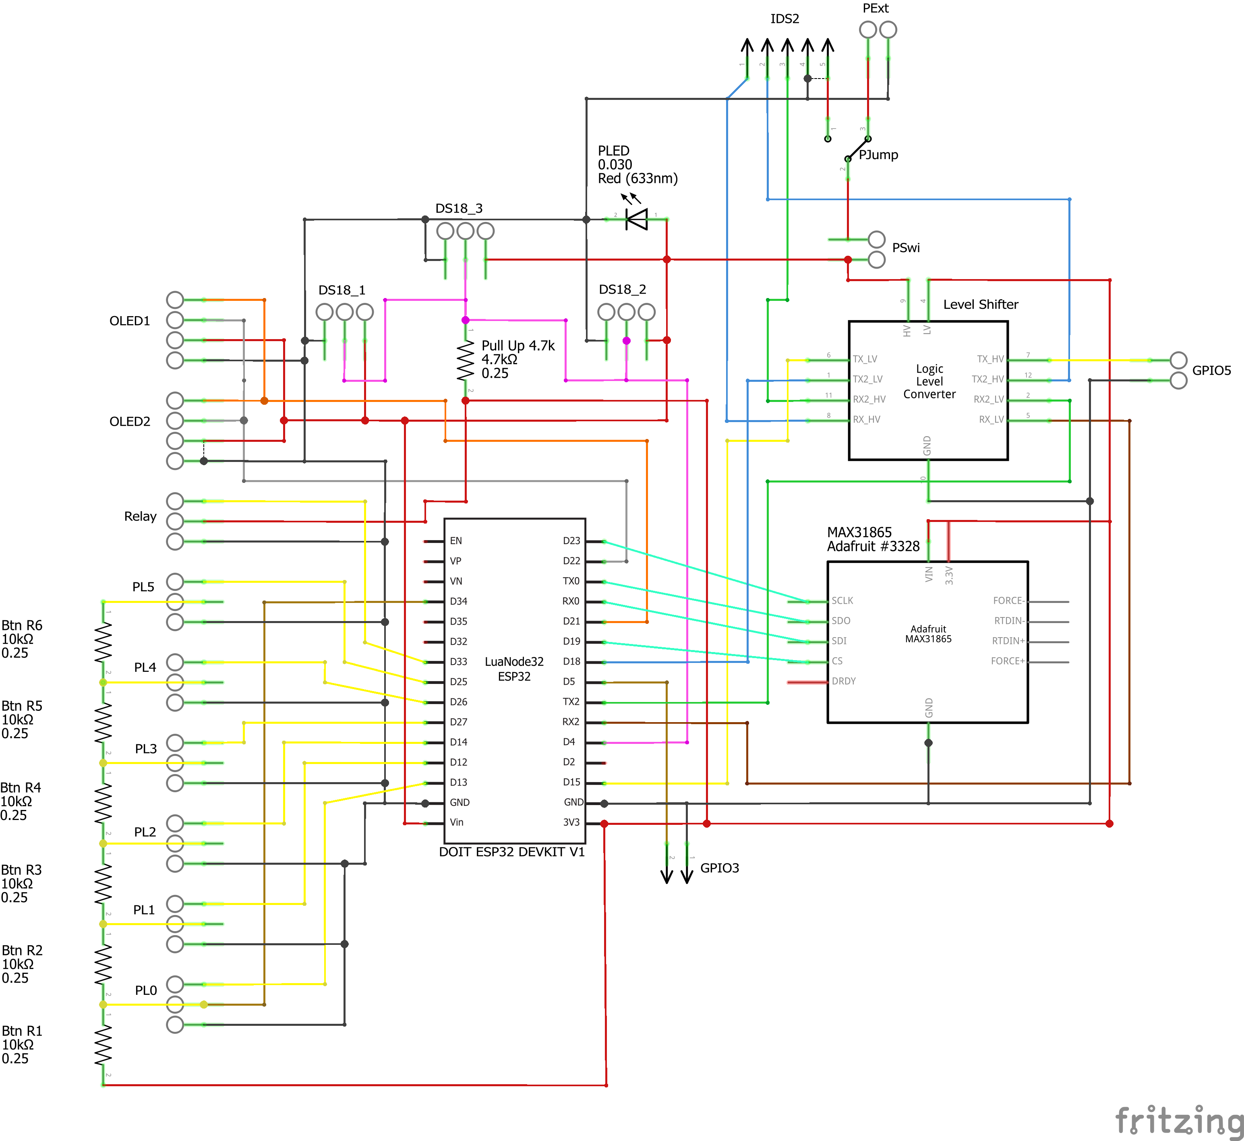
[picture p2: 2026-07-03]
brewingstation/hardware/pcb/brewingstation2_Schaltplan.png

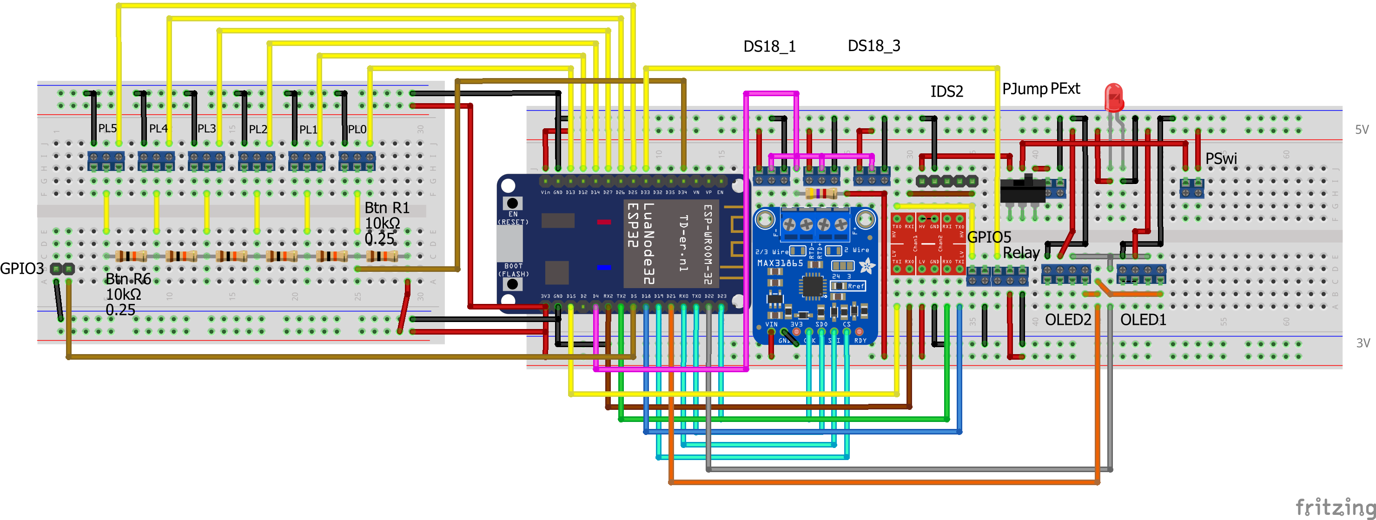
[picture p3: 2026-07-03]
brewingstation/hardware/pcb/brewingstation2_Steckplatine.png

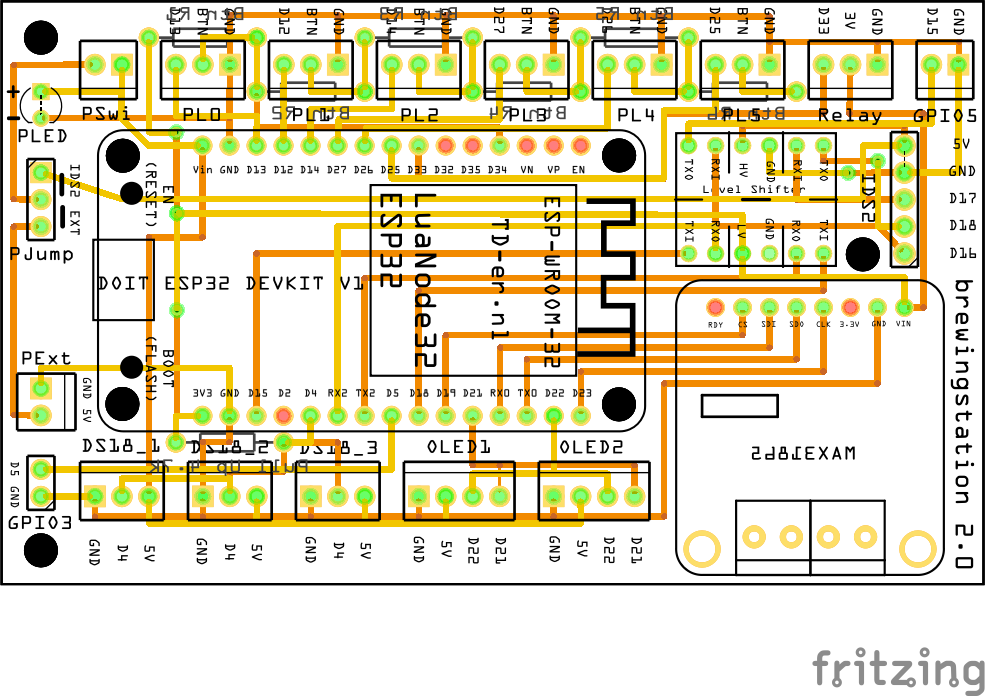
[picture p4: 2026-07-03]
brewingstation/hardware/pcb/brewingstation2_Leiterplatte.png

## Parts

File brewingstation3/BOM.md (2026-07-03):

# Brewing Station 3 — Bill of Materials

---

## Main boards & modules

| Ref | Component | Qty | Description | Source |
|---|---|---|---|---|
| U1 | ESP32-C6-DevKitC-1-N8 | 1 | ESP32-C6 dev board, 8MB flash, USB-CDC built-in | [**ESP32-C6DEVKI1N8**](https://www.reichelt.de/de/de/shop/produkt/entwicklungsboard_esp32-c6-wroom-1_u-380385) — Reichelt |
| U2 | PCF8574 | 1 | I2C GPIO expander, DIP-16 | [**PCF 8574 N**](https://www.reichelt.de/de/de/shop/produkt/remote_8-bit_i_o_expander_for_i2c_bus_pdip-16-216402) — Reichelt |
| U3 | BSS138 4-ch level shifter module | 1 | Bidirectional 3.3V↔5V, 2×4 pin module | AliExpress — search "BSS138 level shifter 4 channel"; Reichelt alternative: [**DEBO LOGIC 4CH**](https://www.reichelt.de/de/de/shop/produkt/entwicklerboards_-_bidirektionaler_logikpegelkonverter_4-kanal_-235503) |
| U5 | MAX31865 module | 1 | PT100/PT1000 RTD amplifier, SPI, 7-pin module | AliExpress — search "MAX31865 module" |
| U6 | BME680 breakout | 1 | Temp / humidity / pressure / gas, 6-pin SPI module. Adafruit-compatible pinout (19×17mm). Mount through case cutout. | AliExpress clone (Adafruit-similar) — search "BME680 module SPI I2C"; Reichelt alternative: [**DEBO SENS BME680**](https://www.reichelt.de/de/de/shop/produkt/entwicklerboards_-_sensor_bosch_bme680-253653) — JOY-IT, 30×14mm, verify pinout before ordering |
| K1 | Relay module | 1 | Single-channel, **3.3V-compatible** opto input, NO/NC/COM screw terminals on load side | AliExpress — search "5V relay module 3.3V trigger" |
| DS1, DS2 | SSD1306 OLED 128×64 | 2 | I2C, 4-pin (GND/VCC/SCL/SDA), 0.96". DS1 = 0x3C, DS2 = 0x3D (ADDR pin high) | AliExpress |
| — | GGM IDS2 induction cooker | 1 | Induction cooker with WHITE/YELLOW/BLUE control cable | GGM Gastro |

---

## Probes & case connectors

| Ref | Component | Qty | Description | Source |
|---|---|---|---|---|
| — | DS18B20 probe | 3 | Food-safe stainless steel, silicone cable (lebensmittelecht), OneWire | AliExpress — search "DS18B20 stainless steel silicone food safe" |
| — | PT1000 probe | 1 | Food-safe stainless steel, silicone cable (lebensmittelecht), 4-wire | AliExpress — search "PT1000 stainless steel silicone food safe 4-wire" |
| — | GX12 4-pin aviation connector | 3 | Panel-mount connectors for DS18B20 probes — not on PCB, mounted in case | [Amazon B09WY7KFB6](https://www.amazon.de/gp/product/B09WY7KFB6/) — Aiqeer, 5× 4-pin GX12, M12 thread |

---

## Discrete components (PCB)

| Ref | Component | Qty | Description | Source |
|---|---|---|---|---|
| BZ1 | Magnetic buzzer (active) | 1 | **SUMMER CPM 121**, Ø14mm, RM7.6mm, 3–16V DC, internal oscillator — on/off switching via Q1 NPN | [**SUMMER CPM 121**](https://www.reichelt.de/de/de/shop/produkt/piezosummer-35924) — Reichelt |
| Q1 | BC547B | 1 | NPN transistor, TO-92, buzzer driver | [**BC 547B**](https://www.reichelt.de/de/de/shop/produkt/bipolartransistor_npn_45v_0_1a_0_5w_to-92-5006) — Reichelt |
| R1 | 4.7kΩ 0.6W metal film | 1 | OneWire pull-up for DS18B20 bus | [**METALL 4,70K**](https://www.reichelt.de/de/de/shop/produkt/widerstand_metallschicht_4_70_kohm_0207_0_6_w_1_-11784) — Reichelt |
| R2–R7, R15, R16 | 330Ω 0.6W metal film | 8 | LED current limiters (PCF8574 P0–P5 → J15–J20 pin 3; P6/P7 → J21/J22 pin 2) | [**METALL 330**](https://www.reichelt.de/de/de/shop/produkt/widerstand_metallschicht_330_ohm_0207_0_6_w_1_-11733) — Reichelt |
| R8 | 1kΩ 0.6W metal film | 1 | Base resistor for buzzer NPN driver | [**METALL 1,00K**](https://www.reichelt.de/de/de/shop/produkt/widerstand_metallschicht_1_00_kohm_0207_0_6_w_1_-11403) — Reichelt |
| R17 | 470Ω 0.6W thin film | 1 | Power switch LED current limiter (PSOURCE_OUT → SW1 LED+) | [**DÜNNS 470**](https://www.reichelt.de/de/de/shop/produkt/duennschichtwiderstand_axial_0_6_w_470_ohm_1_-233741) — Reichelt |
| R9 | 10kΩ 0.6W metal film | 1 | Button ladder pull-up (3V3 → ADC_BTN) | [**METALL 10,0K**](https://www.reichelt.de/de/de/shop/produkt/widerstand_metallschicht_10_00_kohm_0207_0_6_w_1_-11449) — Reichelt |
| R10 | 39kΩ 0.6W metal film | 1 | Button ladder — BTN1 (0% power) | [**METALL 39,0K**](https://www.reichelt.de/de/de/shop/produkt/widerstand_metallschicht_39_0_kohm_0207_0_6_w_1_-11766) — Reichelt |
| R11 | 33kΩ 0.6W metal film | 1 | Button ladder — BTN2 (20% power) | [**METALL 33,0K**](https://www.reichelt.de/de/de/shop/produkt/widerstand_metallschicht_33_0_kohm_0207_0_6_w_1_-11730) — Reichelt |
| R12 | 22kΩ 0.6W metal film | 1 | Button ladder — BTN3 (40% power) | [**METALL 22,0K**](https://www.reichelt.de/de/de/shop/produkt/widerstand_metallschicht_22_0_kohm_0207_0_6_w_1_-11622) — Reichelt |
| R13 | 12kΩ 0.6W metal film | 1 | Button ladder — BTN4 (60% power) | [**METALL 12,0K**](https://www.reichelt.de/de/de/shop/produkt/widerstand_metallschicht_12_0_kohm_0207_0_6_w_1_-11482) — Reichelt |
| R14 | 3.3kΩ 0.6W metal film | 1 | Button ladder — BTN5 (80% power) | [**METALL 3,30K**](https://www.reichelt.de/de/de/shop/produkt/widerstand_metallschicht_3_30_kohm_0207_0_6_w_1_-11693) — Reichelt |

---

## Button + LED panel (external — not on PCB)

6 momentary NO push-buttons wired to J15–J20. All pull-up and ladder resistors (R9–R14) are on the PCB — the panel carries only bare switches.

| Component | Qty | Description | Source |
|---|---|---|---|
| Momentary NO push-button | 6 | Panel-mount, any style (SW2–SW7) | — |

---

## Connectors & terminals

Phoenix Contact MPT 0,5/X-2,54 screw terminals are available in 2/3/4/5-pin. For 6-pin U6, install two adjacent 3-pin connectors in the 6-pad footprint (MPT series is joinable at the same pitch).

**2-pin × 6 total** — [**PHC 1725656**](https://www.reichelt.de/de/de/shop/produkt/leiterplattenklemme_2-polig_rm_2_54-60874) — Reichelt

| Ref | Description |
|---|---|
| J3 | PExt external 5V power input |
| J12 | GPIO15 breakout |
| J13 | GPIO10 breakout |
| J14 | GPIO3_ADC breakout |
| J21 | Spare LED P6 |
| J22 | Spare LED P7 |

**3-pin × 11 total** — [**PHC 1725669**](https://www.reichelt.de/de/de/shop/produkt/leiterplattenklemme_3-polig_rm_2_54_mm-60875) — Reichelt

| Ref | Description |
|---|---|
| J7, J8, J9 | DS18B20 sensors ×3 |
| J15–J20 | Button + LED per power level ×6 (0/20/40/60/80/100%) |
| U6 (×2 adjacent) | BME680 module — install two 3-pin connectors side-by-side in the 6-pad footprint |

**4-pin × 3 total** — [**PHC 1725672**](https://www.reichelt.de/de/de/shop/produkt/leiterplattenklemme_4-polig_rm_2_54_mm-60876) — Reichelt

| Ref | Description |
|---|---|
| SW1 | Power switch + integrated LED (SW_A, SW_B, LED+, LED−) |
| DS1, DS2 | SSD1306 OLEDs ×2 |

**5-pin × 1 total** — [**PHC 1725685**](https://www.reichelt.de/de/de/shop/produkt/leiterplattenklemme_5-polig_rm_2_54_mm-255909) — Reichelt

| Ref | Description |
|---|---|
| J1 | GGM IDS2 induction cooker (IDS2_5V, GND, WHITE, YELLOW, BLUE) |

**Other connectors**

| Ref | Component | Qty | Description | Source |
|---|---|---|---|---|
| J4, J10, J11, K1 | Male pin header, 2.54mm | — | Break to length (1×3) | [**SL 1X36G 2,54**](https://www.reichelt.de/de/de/shop/produkt/36pol_stiftleiste_gerade_rm_2_54-19504) — Reichelt |
| U1 | Female socket 1×16, 2.54mm | 2 | DevKit socket — swappable | [**MPE 094-1-016**](https://www.reichelt.de/de/de/shop/produkt/buchsenleisten_2_54_mm_1x16_gerade-119919) — Reichelt |
| U3, U5 | Female socket 1×6/1×7, 2.54mm | 2 | Level shifter + MAX31865 — swappable | [**MPE 094-1-006**](https://www.reichelt.de/de/de/shop/produkt/buchsenleisten_2_54_mm_1x06_gerade-119915) — Reichelt |

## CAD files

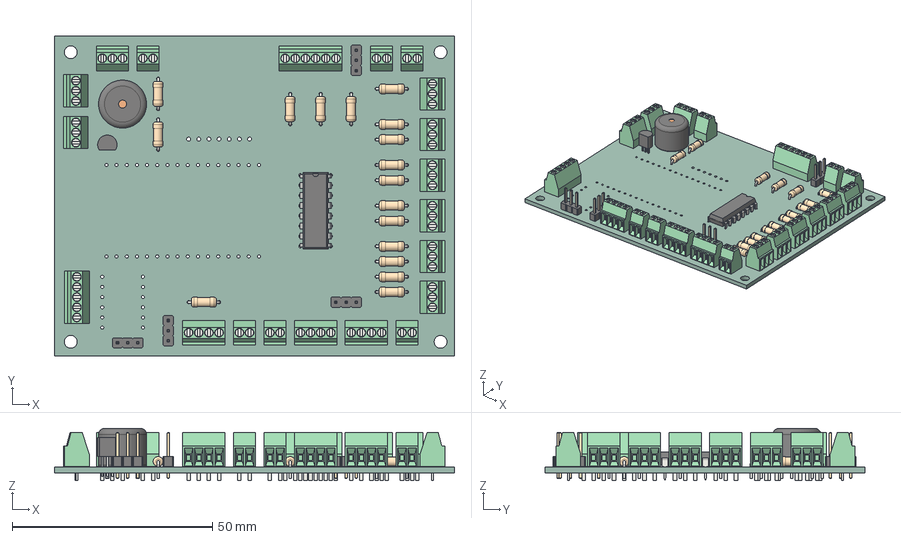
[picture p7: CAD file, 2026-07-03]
brewingstation3/kicad/.step
100.0 x 80.0 x 13.0 mm
TO-92_Inline_Narrow
TerminalBlock_Phoenix_MPT-0,5-6-2.54_1x06_P2.54mm_Horizontal
R_Axial_DIN0207_L63mm_D25mm_P762mm_Horizontal x 17
TerminalBlock_Phoenix_MPT-0,5-4-2.54_1x04_P2.54mm_Horizontal x 3
TerminalBlock_Phoenix_MPT-0,5-2-2.54_1x02_P2.54mm_Horizontal x 6
TerminalBlock_Phoenix_MPT-0,5-5-2.54_1x05_P2.54mm_Horizontal
PinHeader_1x03_P254mm_Vertical x 4
TerminalBlock_Phoenix_MPT-0,5-3-2.54_1x03_P2.54mm_Horizontal x 9
DIP-16_W7.62mm
Buzzer_12x95RM76
brewingstation3_PCB

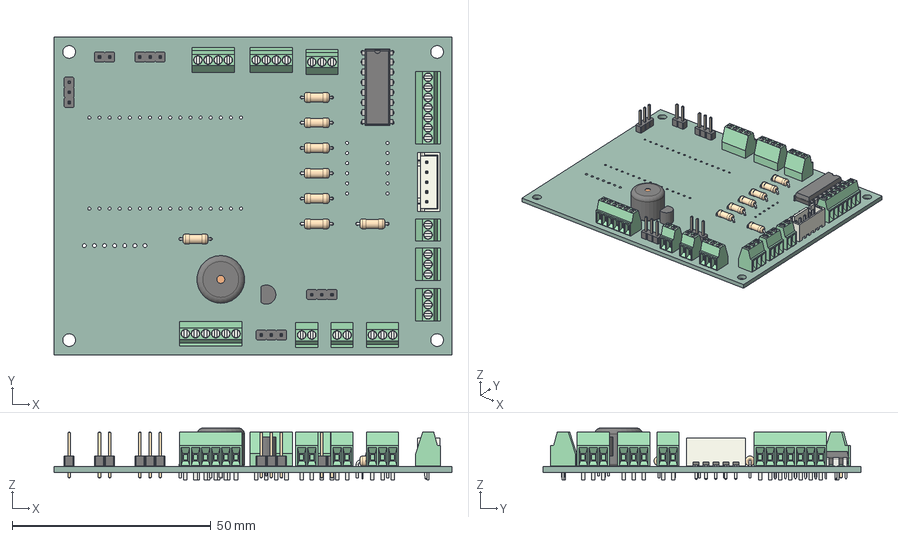
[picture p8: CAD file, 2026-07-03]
brewingstation3/kicad/brewinstation.step
100.0 x 80.0 x 13.0 mm
R_Axial_DIN0207_L63mm_D25mm_P762mm_Horizontal x 8
PinHeader_1x03_P254mm_Vertical x 4
DIP-16_W7.62mm
TerminalBlock_Phoenix_MPT-0,5-2-2.54_1x02_P2.54mm_Horizontal x 3
TerminalBlock_Phoenix_MPT-0,5-3-2.54_1x03_P2.54mm_Horizontal x 4
Buzzer_12x95RM76
TerminalBlock_Phoenix_MPT-0,5-4-2.54_1x04_P2.54mm_Horizontal x 2
JST_B5B_XH_A
TerminalBlock_Phoenix_MPT-0,5-6-2.54_1x06_P2.54mm_Horizontal
TO-92_Inline_Narrow
PinHeader_1x02_P254mm_Vertical
TerminalBlock_Phoenix_MPT-0,5-7-2.54_1x07_P2.54mm_Horizontal
brewingstation3_PCB

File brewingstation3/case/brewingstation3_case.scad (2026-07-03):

// ─────────────────────────────────────────────────────────────────────────────
// Brewstation v3.0 — 3D Printable Case
// PCB: 100 × 80 mm, 1.6 mm thick, 4× M3 corner mounting holes
//
// Two parts:
//   1. tray()  — bottom + four walls, open top
//   2. lid()   — flat top plate with two OLED windows
//
// Lid fastening: 4× M3 screws through lid corners into tray bosses.
//   Tray bosses hold M3 brass heat-set inserts (Ø4.4 mm × 4 mm).
//   Lid has 3.2 mm clearance holes + M3 flat-head countersinks.
//   Recommended screw: M3 × 10 mm flat-head (countersunk).
//
// Print orientation:
//   tray → upright, open top up  (no supports needed)
//   lid  → face up, flat         (no supports needed)
//
// All side holes (USB, connectors, buttons, sensors) are drilled by user.
// Only the two OLED rectangular windows are pre-modelled.
// ─────────────────────────────────────────────────────────────────────────────

// ── Adjustable parameters ─────────────────────────────────────────────────────
pcb_w       = 100;    // PCB width  (X axis, left ↔ right)
pcb_d       = 80;     // PCB depth  (Y axis, front ↔ back)
wall        = 3.0;    // Wall / floor thickness (mm)
lid_t       = 4.0;    // Lid thickness — needs to be ≥ countersink depth
clearance   = 10.0;   // Gap between PCB edge and inner wall (each side)
inner_h     = 84.0;   // Internal cavity height (floor surface → lid underside)
standoff_h  = 12.0;   // PCB standoff height above floor
mh_inset    = 4.0;    // PCB M3 standoff centre inset from each PCB edge

// Lid screw bosses (M3 heat-set insert, Ø4.4 × 4 mm)
boss_r      = 5.5;    // Boss outer radius (11 mm Ø)
boss_h      = 7.0;    // Boss height above tray rim
insert_r    = 2.2;    // Heat-set insert hole radius (4.4 mm Ø for M3)
insert_d    = 4.5;    // Insert hole depth (insert 4 mm + 0.5 mm margin)
screw_r     = 1.6;    // M3 clearance hole radius in lid (3.2 mm Ø)
csk_r       = 2.9;    // M3 flat-head countersink radius (5.8 mm Ø)
csk_d       = 1.8;    // Countersink depth

// OLED window dimensions (0.96" SSD1306 active area ~22 × 11 mm + margin)
oled_cut_w  = 26;
oled_cut_h  = 14;

// OLED window centre positions, measured from inner-left / inner-front corner.
// "front" = top edge of PCB as you look down at the board.
// Adjust oled1_cx / oled2_cx to match where you mount your OLED modules.
oled1_cx    = clearance + 22;   // centre X of left OLED
oled2_cx    = clearance + 57;   // centre X of right OLED
oled_cy     = clearance + 6;    // Y from inner front wall

// ── Derived (do not edit) ─────────────────────────────────────────────────────
inner_w  = pcb_w + 2 * clearance;   // 120 mm
inner_d  = pcb_d + 2 * clearance;   // 100 mm
outer_w  = inner_w + 2 * wall;      // 126 mm
outer_d  = inner_d + 2 * wall;      // 106 mm
tray_h   = wall + inner_h;          //  87 mm outer tray height

// Boss centres at the four outer corners of the box
boss_pos = [
    [ boss_r,           boss_r           ],
    [ outer_w - boss_r, boss_r           ],
    [ boss_r,           outer_d - boss_r ],
    [ outer_w - boss_r, outer_d - boss_r ],
];

// PCB corner standoff positions in inner-cavity coordinates
mh_pos = [
    [ clearance + mh_inset,         clearance + mh_inset         ],
    [ clearance + pcb_w - mh_inset, clearance + mh_inset         ],
    [ clearance + mh_inset,         clearance + pcb_d - mh_inset ],
    [ clearance + pcb_w - mh_inset, clearance + pcb_d - mh_inset ],
];

// ─────────────────────────────────────────────────────────────────────────────
// TRAY
// ─────────────────────────────────────────────────────────────────────────────
module tray() {
    difference() {
        union() {
            // Outer shell
            cube([outer_w, outer_d, tray_h]);
            // Screw bosses — protrude above tray rim to receive lid screws
            for (p = boss_pos)
                translate([p[0], p[1], tray_h])
                    cylinder(h = boss_h, r = boss_r, $fn = 48);
        }
        // Hollow interior — floor stays, top is open
        translate([wall, wall, wall])
            cube([inner_w, inner_d, tray_h]);
        // Heat-set insert holes — drilled down from top of each boss
        for (p = boss_pos)
            translate([p[0], p[1], tray_h + boss_h])
                mirror([0, 0, 1])
                    cylinder(h = insert_d, r = insert_r, $fn = 32);
    }

    // PCB corner standoffs — solid, user drills M3 pilot if needed
    for (p = mh_pos)
        translate([wall + p[0], wall + p[1], wall])
            cylinder(h = standoff_h, r = 4.0, $fn = 32);
}

// ─────────────────────────────────────────────────────────────────────────────
// LID
// ─────────────────────────────────────────────────────────────────────────────
module lid() {
    difference() {
        // Flat plate, same footprint as tray
        cube([outer_w, outer_d, lid_t]);

        // M3 clearance holes + countersinks at boss positions
        for (p = boss_pos) {
            // Clearance hole through full lid thickness
            translate([p[0], p[1], -0.1])
                cylinder(h = lid_t + 0.2, r = screw_r, $fn = 32);
            // Countersink from top face
            translate([p[0], p[1], lid_t - csk_d])
                cylinder(h = csk_d + 0.1, r1 = screw_r, r2 = csk_r, $fn = 32);
        }

        // OLED window 1 (left display)
        translate([wall + oled1_cx - oled_cut_w/2,
                   wall + oled_cy,
                   -0.1])
            cube([oled_cut_w, oled_cut_h, lid_t + 0.2]);

        // OLED window 2 (right display)
        translate([wall + oled2_cx - oled_cut_w/2,
                   wall + oled_cy,
                   -0.1])
            cube([oled_cut_w, oled_cut_h, lid_t + 0.2]);
    }
}

// ─────────────────────────────────────────────────────────────────────────────
// RENDER — side by side for slicer import
// Comment out one module to export parts individually as STL.
// ─────────────────────────────────────────────────────────────────────────────
tray();
translate([outer_w + 20, 0, 0]) lid();

// ─────────────────────────────────────────────────────────────────────────────
// Key dimensions:
//   Outer footprint  : 126 × 106 mm
//   Total height     :  90 mm (tray 87 mm + lid 4 mm, bosses 7 mm above rim)
//   Internal cavity  : 120 × 100 × 84 mm
//   PCB sits at      :  15 mm from floor (3 mm floor + 12 mm standoffs)
//   Wire space below : 12 mm  |  Wire space above: ~70 mm
//   Fasteners        : 4× M3 × 10 mm flat-head + M3 brass heat-set inserts
// ─────────────────────────────────────────────────────────────────────────────

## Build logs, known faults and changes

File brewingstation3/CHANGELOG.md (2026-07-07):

# Changelog

All notable changes to brewingstation3 (V3) are documented here.
Format follows [Keep a Changelog](https://keepachangelog.com/en/1.1.0/).

## [Unreleased]

### Added
- MQTT Last Will and Testament: the broker now publishes a retained "offline"
  on `{root}/{device}/availability` if the device drops off without a clean
  disconnect (crash, power loss, WiFi drop), and the device publishes a
  retained "online" on the same topic once connected (both at startup and
  after every reconnect). Lets any subscriber — CraftBeerPi, a future Home
  Assistant integration, or a plain `mosquitto_sub` — detect device loss
  directly instead of inferring it from a stale `device` status topic.

## [3.0.0-alpha.3] - 2026-07-07

### Added
- Extracted more hardware-independent logic into `pure_logic.h` for native unit
  testing: induction power→PWM-level math (`computePowerLevel`), the RX pulse
  classifier and frame decoder (`classifyPulse`/`decodeErrorCode`), the brew
  timer as a testable state machine (`BrewTimerState`), safety predicates
  (`sensorIsHealthy`/`isThermalRunaway`), and display row-1 formatting
  (`computeRow1Display`). 31 new tests (45 total). No behavior change.
- Settings persistence via LittleFS: power cap, device mode, and PID
  state/tunings/setpoint now survive a reboot instead of reverting to
  `config.h` defaults. Saved to `/settings.json` whenever changed via MQTT,
  reloaded at boot after `setup_pid()`.
- WiFiManager captive-portal provisioning, replacing the hardcoded
  `SSID_NAME`/`SSID_PASSWORD` + reboot-on-fail Wi-Fi connect. Opens
  automatically on first boot or a failed connect, or can be forced by
  holding any panel button for ~2s at power-on. The same portal now also
  provisions the MQTT broker address, MQTT topic prefix (root/device), and
  OTA password as runtime-configurable custom fields (persisted to
  `/netconfig.json`) — these no longer require a reflash to change. The 13
  MQTT subscribe-topic strings were converted from compile-time macros to
  runtime buffers to support this.
- Board's partition table switched from the stock 4MB scheme to
  `default_8MB.csv` to match the actual N8 (8MB flash) module — each OTA
  app slot grows from 1.25MB to ~3.19MB and LittleFS from 1.4MB to 1.5MB,
  needed to make room for WiFiManager and future web-dashboard work.
- Built-in web server (`WebServer`/`Update`, both bundled with the
  arduino-esp32 core — no new `lib_deps`) exposing three tabbed pages
  under a shared nav bar:
  - `/` — read-only status dashboard (sensors, setpoint, PID/mode,
    induction power/cap, relay, GPIO5, brew timer, RSSI, uptime, free
    heap, version), auto-refreshes every 5s.
  - `/update` — browser-based firmware upload form; streams straight
    into the inactive OTA partition via the `Update` library, then
    reboots.
  - `/config` — current runtime configuration (MQTT broker/topic
    prefix, WiFi SSID/IP, power cap, device mode, PID tunings/setpoint;
    OTA password masked), with a "Download config (.json)" link
    (`/config/download`) that exports the same data — including the
    plaintext OTA password — as a downloadable JSON file for backup.
  `/update` and `/config` (+ its download) are gated behind HTTP Basic
  Auth using the same `cfgOtaPassword` ArduinoOTA already uses; `/` is
  unauthenticated (read-only, no secrets). The shared nav bar shows the
  hostname and current firmware version, with a yellow "pre-release"
  warning badge next to the version when it's an alpha/beta build
  (`isPrereleaseVersion()` in `pure_logic.h`). The `/update` page also
  links to the project's GitHub releases page and has a "Check for
  update" button that runs entirely in the browser (`fetch()` against
  the GitHub releases API, filtered to `3.*` tags, compared against
  the running version) — no TLS/HTTPS client added to the firmware
  itself.
- Extracted two more small pure functions into `pure_logic.h` for
  native testing: `deviceModeName()` (was duplicated inline as
  `deviceMode == MODE_SLAVE ? "slave" : "standalone"` at 5 call sites
  across MQTT status, OLED display, and the new web pages) and
  `isPrereleaseVersion()` (used by the nav bar badge above). 5 new
  tests (50 total).

## [3.0.0-alpha.2] - 2026-07-07

### Fixed
- 8 bugs from a full code review: out-of-bounds write in
  `induction::readInput()`, `pid/reset` not actually resetting PID_v1's
  internal state, unvalidated MQTT JSON payload types, button power-cap
  bypass, `millis()` 32-bit wraparound handling (new `deadlineReached()`
  helper, used at all 8 timing sites), missing `IRAM_ATTR` on an ISR,
  an ISR race in `setup_induction()`, and a sensor-staleness blind spot
  for PID sensors other than DS18B20.
- 4 judgment-call issues from the same review: fragile float-equality
  sensor fault detection (replaced with a threshold), timer-expiry check
  decoupled from the display refresh rate, redundant self-subscription
  removed, and `pid/enable` no longer accepted while in slave mode.
- Regenerated `include/config.h` pin layout, which had drifted to an
  earlier "custom carrier PCB" board revision with two dangerous pin
  choices (a boot-strapping pin used for the relay, a non-exposed pin
  for the spare GPIO).

### Added
- OTA update workflow and a full 10-stage post-assembly bring-up checklist
  (power-on, sensors, induction cooker, buttons/LEDs, PID tuning, safety
  systems, buzzer, timer/MQTT control, case fit, soak test) to the backlog.
- Release notes are now sourced from this changelog instead of
  auto-generated commit/PR lists.

### Removed
- Stray tracked KiCad tooling backup files (`.mcp-backups/`,
  `_restore_backup_*/`, `kicad.zip`).

## [3.0.0-alpha.1] - 2026-07-03

First tagged pre-release. Firmware compiles and passes its unit tests, but
the hardware has not been assembled yet (PCB unsoldered, case unprinted,
nothing tested end-to-end).

### Added
- Buzzer firmware (LEDC PWM tone/alarm for step-complete and safety alarms).
- Two-point linear calibration for DS18B20, MAX31865, and BME680 sensors.
- Native unit tests (PlatformIO `native` environment) covering calibration,
  button-bucket mapping, and induction error-code logic.
- Versioning/release workflow: `3.*` tag scheme (kept separate from V1's
  plain `vX.Y.Z` tags), published as a GitHub prerelease.

### Changed
- Firmware explicitly marked as work-in-progress (`VERSION` string,
  README/CLAUDE.md notes) to signal untested hardware status.

[Unreleased]: https://github.com/Gr3yh0und/brewingstation/compare/3.0.0-alpha.3...HEAD
[3.0.0-alpha.3]: https://github.com/Gr3yh0und/brewingstation/compare/3.0.0-alpha.2...3.0.0-alpha.3
[3.0.0-alpha.2]: https://github.com/Gr3yh0und/brewingstation/compare/3.0.0-alpha.1...3.0.0-alpha.2
[3.0.0-alpha.1]: https://github.com/Gr3yh0und/brewingstation/releases/tag/3.0.0-alpha.1

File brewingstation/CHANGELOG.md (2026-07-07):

# Changelog

All notable changes to brewingstation (V1) are documented here.
Format follows [Keep a Changelog](https://keepachangelog.com/en/1.1.0/).

## [Unreleased]

## [1.13.0] - 2026-07-03

Initial tagged release. One firmware, byte-identical across both hardware
variants (breadboard and custom PCB).

### Added
- PlatformIO support (`esp32doit-devkit-v1` environment) alongside the
  existing Arduino IDE compatibility.
- `hardware/breadboard/` and `hardware/pcb/` variant folders, merging
  brewingstation2 into brewingstation as a hardware variant of the same
  firmware rather than a separate maintained copy.
- README, `.gitignore`, and VS Code tooling brought up to brewingstation3's
  documentation/tooling conventions.

### Fixed
- Hardcoded `"cave/brewery"` MQTT topic strings replaced with topics built
  from the configurable `MQTT_ROOT_PATH`/`MQTT_DEVICE` values.
- `strcmp(topic, TOPIC_PID_ROOT) == 1` typo in the debug-build `mqttCallback`
  (should be `== 0`), which silently broke PID-topic matching in debug
  builds.

[Unreleased]: https://github.com/Gr3yh0und/brewingstation/compare/v1.13.0...HEAD
[1.13.0]: https://github.com/Gr3yh0und/brewingstation/releases/tag/v1.13.0

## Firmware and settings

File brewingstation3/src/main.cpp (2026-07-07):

#include <Arduino.h>
// Automated beer brewing station — ESP32-C6 edition
// Controls a GGM IDS2 induction cooker via PID temperature control
// Compatible with CraftBeerPi 3 and 4
// Induction cooker protocol based on: https://github.com/InnuendoPi/MQTTDevice2
// Michael Morscher — Board: ESP32-C6-WROOM-1U
#include <WiFi.h>
#include <WiFiUdp.h>
#include <time.h>
#include "esp_task_wdt.h"
#include <Wire.h>
#include <SPI.h>
#include <ArduinoOTA.h>
#include <ESPmDNS.h>
#include <PubSubClient.h>
#include <ArduinoJson.h>
#include <LittleFS.h>
#include <WiFiManager.h>
#include <WebServer.h>
#include <Update.h>
#include <Syslog.h>
#include <arduino-timer.h>
#include <OneWire.h>
#include <DallasTemperature.h>
#include <Adafruit_Sensor.h>
#include <Adafruit_MAX31865.h>
#include <Adafruit_BME680.h>
#include <PID_v1.h>
#include <Adafruit_GFX.h>
#include <Adafruit_SSD1306.h>
#include <Fonts/FreeSans9pt7b.h>
#include <Fonts/FreeSans18pt7b.h>
#include <Fonts/FreeSans24pt7b.h>
#include <PCF8574.h>
#include "config.h"
#include "pure_logic.h"

#define VERSION "3.0.0-alpha.3"

// Forward declarations
void setLED(int value);
void ledEmergencyBlink();
void relay_write_mqtt();
void gpio5_write_mqtt();
void buzzerAlarm();
void buzzerBeep();

// Feature toggles — use 0/1 so #if directives work correctly
#define SERIAL_ENABLE  0
#define MQTT_ENABLE    1
#define PUBLISH_ENABLE 1

// Operating modes
#define MODE_STANDALONE 0  // local PID computes and drives induction power
#define MODE_SLAVE      1  // power driven entirely by heater/power MQTT commands

// Sensor limits
#define SENSOR_MAXIMUM        5
#define SENSOR_MQTT_PREFIX    "sensor"    // publish root: {root}/{device}/sensor/{N}
// MAX31865 reports ~-242.02f when the RTD is open-circuit (extrapolated from a maxed-out
// fault reading). Compared with a threshold rather than exact equality: the value is
// deterministic for a given R_NOM/R_REF pair, but exact float equality is fragile across
// library versions/compilers, so anything unrealistically cold is treated as "no sensor".
#define PT100X_FAULT_THRESHOLD -240.0f

// Display
#define TEXT_ROW_HEIGHT_PX 10  // pixel height per row in the default (NULL) font

// Subscribe-side topics — runtime buffers, not compile-time macros: the root path/device
// name are now provisionable via the WiFiManager portal (cfgMqttRoot/cfgMqttDevice, up to
// 23 chars each), so they can't be pasted together by the preprocessor. Pre-computed once
// in setup() (after loadNetConfig()), same pattern as the PUBLISH_TOPIC_* buffers below.
// Sized for the worst case (23 + '/' + 23 + longest suffix "/induction/cap" = 61) + margin.
char TOPIC_INDUCTION_SET[72];
char TOPIC_INDUCTION_CAP[72];
// "+" (single-level wildcard), not "#": all pid subtopics are one level deep, and "#"
// also matches the bare "pid" topic itself — which is where this device publishes its
// own status every FREQUENCY_STATUS ms, causing a pointless publish->subscribe->parse
// round-trip of its own messages.
char TOPIC_PID_WILDCARD[72];
char TOPIC_PID_ENABLE[72];
char TOPIC_PID_RESET[72];
char TOPIC_PID_P[72];
char TOPIC_PID_I[72];
char TOPIC_PID_D[72];
char TOPIC_PID_SETPOINT[72];
char TOPIC_TIMER_SET[72];
char TOPIC_TIMER_CTL[72];
char TOPIC_DEVICE_MODE[72];
char TOPIC_RELAY_SET[72];
char TOPIC_GPIO5_SET[72];

// Publish-side topics — pre-computed in setup() to avoid per-call heap allocations.
// Same worst-case sizing rationale as the subscribe-side buffers above.
char PUBLISH_TOPIC_SENSOR_PREFIX[72];  // e.g. "{root}/{device}/sensor/"
char PUBLISH_TOPIC_INDUCTION[72];      // e.g. "{root}/{device}/induction"
char PUBLISH_TOPIC_PID[72];            // e.g. "{root}/{device}/pid"
char PUBLISH_TOPIC_TIMER[72];          // e.g. "{root}/{device}/timer"
char PUBLISH_TOPIC_DEVICE[72];         // e.g. "{root}/{device}/device"
char PUBLISH_TOPIC_RELAY[72];          // e.g. "{root}/{device}/relay"
char PUBLISH_TOPIC_GPIO5[72];          // e.g. "{root}/{device}/gpio5"
char PUBLISH_TOPIC_AVAILABILITY[72];   // e.g. "{root}/{device}/availability" — LWT + retained "online"/"offline"

// PCF8574 I2C GPIO expander — drives all 6 power LEDs
PCF8574 ledExpander(PCF8574_ADDR);

// Sensors & Displays
OneWire oneWire(SENSOR_BUS_PIN);
DallasTemperature sensorlist(&oneWire);
Adafruit_MAX31865 pt100x = Adafruit_MAX31865(SENSOR_PT100X_CS_PIN, SENSOR_PT100X_DI_PIN, SENSOR_PT100X_DO_PIN, SENSOR_PT100X_CLK_PIN);
bool pt100x_found = false;
Adafruit_BME680 bme680(SENSOR_BME680_CS_PIN, SENSOR_BME680_DI_PIN, SENSOR_BME680_DO_PIN, SENSOR_BME680_CLK_PIN);
bool bme680_found = false;
Adafruit_SSD1306 display(DISPLAY_SCREEN_WIDTH, DISPLAY_SCREEN_HEIGHT, &Wire, DISPLAY_OLED_RESET);
Adafruit_SSD1306 display2(DISPLAY_SCREEN_WIDTH, DISPLAY_SCREEN_HEIGHT, &Wire, DISPLAY_OLED_RESET);

// WiFi icon bitmap (24x24)
const uint8_t bitmap26[] = { 0x00, 0x00, 0x00, 0x00, 0x00, 0x00, 0x00, 0x00, 0x00, 0x00, 0x00, 0x00, 0x01, 0xff, 0x80, 0x07, 0xff, 0xe0, 0x1f, 0x81, 0xf8, 0x7c, 0x00, 0x3e, 0xf0, 0x00, 0x0f, 0xe0, 0xff, 0x07, 0x03, 0xff, 0xc0, 0x0f, 0xe7, 0xf0, 0x0f, 0x00, 0xf0, 0x08, 0x00, 0x10, 0x00, 0x7e, 0x00, 0x00, 0xff, 0x00, 0x00, 0xe7, 0x00, 0x00, 0x00, 0x00, 0x00, 0x00, 0x00, 0x00, 0x18, 0x00, 0x00, 0x18, 0x00, 0x00, 0x00, 0x00, 0x00, 0x00, 0x00, 0x00, 0x00, 0x00 };
// MQTT message received icon bitmap (24x24)
const uint8_t bitmap27[] = { 0x00, 0x00, 0x00, 0x00, 0x00, 0x00, 0x00, 0x18, 0x00, 0x00, 0x18, 0x00, 0x00, 0x18, 0x00, 0x00, 0x18, 0x00, 0x00, 0x18, 0x00, 0x00, 0x18, 0x00, 0x00, 0x18, 0x00, 0x03, 0x18, 0xc0, 0x03, 0x99, 0x80, 0x01, 0xdb, 0x80, 0x00, 0xff, 0x00, 0x00, 0x7e, 0x00, 0x30, 0x3c, 0x0c, 0x30, 0x18, 0x0c, 0x30, 0x00, 0x0c, 0x30, 0x00, 0x0c, 0x30, 0x00, 0x0c, 0x38, 0x00, 0x1c, 0x3f, 0xff, 0xfc, 0x1f, 0xff, 0xf8, 0x00, 0x00, 0x00, 0x00, 0x00, 0x00 };
bool display_toggle = true;

// Button resistor ladder — single analog pin, 6 buttons mapped by ADC threshold
#define BUTTON_PIN         BUTTON_ADC_PIN
#define BUTTON_DEBOUNCE_MS 250
int lastButtonBucket = 0;
unsigned long lastButtonChange = 0;

// Induction cooker serial protocol timing constants — SIGNAL_HIGH/LOW(_TOL) live
// in pure_logic.h (shared with the testable pulse classifier); these two are only
// used for shaping the outgoing start pulse and aren't part of that logic.
const int SIGNAL_START    = 25;
const int SIGNAL_WAIT     = 10;

// PID controller
#define PID_MQTT_TOPIC "pid"
double PID_Setpoint;
double PID_Input;
double Output;
const double Output_Limit_Max = 100;
const double Output_Limit_Min = 0;
double PID_P = PID_DEFAULT_P;
double PID_I = PID_DEFAULT_I;
double PID_D = PID_DEFAULT_D;
bool PID_state        = false;
bool pidTuningsDirty  = false;  // set when P/I/D change; cleared after SetTunings() is called
PID myPID(&PID_Input, &Output, &PID_Setpoint, PID_P, PID_I, PID_D, P_ON_M, DIRECT);

// Network
const char *hostname = HOSTNAME;
WiFiManager wm;
WiFiClient wifiClient;
WiFiUDP udpClient;
PubSubClient mqttClient(wifiClient);
WebServer webServer(80);
bool webUpdateInProgress = false;
bool webUpdateFailed     = false;

// Runtime-configurable network/identity settings — provisioned via the WiFiManager portal's
// custom parameters (see setup()) instead of being fixed at compile time. Seeded from
// config.h so first boot (no /netconfig.json yet) behaves exactly as before.
char cfgMqttBroker[40]  = BROKER_ADDRESS;
char cfgMqttRoot[24]    = MQTT_ROOT_PATH;
char cfgMqttDevice[24]  = MQTT_DEVICE;
char cfgOtaPassword[32] = OTA_PASSWORD;
Syslog syslog(udpClient, SYSLOG_SERVER, SYSLOG_PORT, hostname, SYSLOG_APP_NAME, LOG_KERN);
bool message_received = false;

// Fills in the runtime TOPIC_* buffers (declared above, near the induction cooker's
// legacy compile-time defines) from cfgMqttRoot/cfgMqttDevice. Must run after
// loadNetConfig() and before subscribe_topics()/mqttCallback() are ever reachable.
void computeSubscribeTopics() {
  snprintf(TOPIC_INDUCTION_SET, sizeof(TOPIC_INDUCTION_SET), "%s/%s/induction/set", cfgMqttRoot, cfgMqttDevice);
  snprintf(TOPIC_INDUCTION_CAP, sizeof(TOPIC_INDUCTION_CAP), "%s/%s/induction/cap", cfgMqttRoot, cfgMqttDevice);
  snprintf(TOPIC_PID_WILDCARD,  sizeof(TOPIC_PID_WILDCARD),  "%s/%s/pid/+",         cfgMqttRoot, cfgMqttDevice);
  snprintf(TOPIC_PID_ENABLE,    sizeof(TOPIC_PID_ENABLE),    "%s/%s/pid/enable",    cfgMqttRoot, cfgMqttDevice);
  snprintf(TOPIC_PID_RESET,     sizeof(TOPIC_PID_RESET),     "%s/%s/pid/reset",     cfgMqttRoot, cfgMqttDevice);
  snprintf(TOPIC_PID_P,         sizeof(TOPIC_PID_P),         "%s/%s/pid/p",         cfgMqttRoot, cfgMqttDevice);
  snprintf(TOPIC_PID_I,         sizeof(TOPIC_PID_I),         "%s/%s/pid/i",         cfgMqttRoot, cfgMqttDevice);
  snprintf(TOPIC_PID_D,         sizeof(TOPIC_PID_D),         "%s/%s/pid/d",         cfgMqttRoot, cfgMqttDevice);
  snprintf(TOPIC_PID_SETPOINT,  sizeof(TOPIC_PID_SETPOINT),  "%s/%s/pid/setpoint",  cfgMqttRoot, cfgMqttDevice);
  snprintf(TOPIC_TIMER_SET,     sizeof(TOPIC_TIMER_SET),     "%s/%s/timer/set",     cfgMqttRoot, cfgMqttDevice);
  snprintf(TOPIC_TIMER_CTL,     sizeof(TOPIC_TIMER_CTL),     "%s/%s/timer/ctl",     cfgMqttRoot, cfgMqttDevice);
  snprintf(TOPIC_DEVICE_MODE,   sizeof(TOPIC_DEVICE_MODE),   "%s/%s/device/mode",   cfgMqttRoot, cfgMqttDevice);
  snprintf(TOPIC_RELAY_SET,     sizeof(TOPIC_RELAY_SET),     "%s/%s/relay/set",     cfgMqttRoot, cfgMqttDevice);
  snprintf(TOPIC_GPIO5_SET,     sizeof(TOPIC_GPIO5_SET),     "%s/%s/gpio5/set",     cfgMqttRoot, cfgMqttDevice);
}

// Timers
Timer<> timerTempStatus;
Timer<> timerTempRead;
Timer<> timerInductionStatus;
Timer<> timerDisplayUpdate;

// Operating mode
int deviceMode = DEVICE_MODE_DEFAULT;

// Power cap — runtime-adjustable ceiling applied to all induction output paths
int powerCap = INDUCTION_POWER_CAP;

// General-purpose relay
bool relayState       = false;
unsigned long relayTimerEndMs = 0;  // 0 = no active timer

// Extra GPIO (GPIO5 connector)
bool gpio5State           = false;
unsigned long gpio5TimerEndMs = 0;

// Brew timer — state machine lives in pure_logic.h (BrewTimerState) so it's
// unit-testable, including wraparound, with an injected `now`.
BrewTimerState brewTimer;

unsigned long timerRemainingMs() {
  return brewTimerRemainingMs(brewTimer, millis());
}

// Detects brew-timer expiry independent of the display refresh cadence — called every
// loop() iteration so expiry can't be delayed by DISPLAY_FREQUENCY, and status publishes
// (timer_write_mqtt) never observe a stale "running:1, remaining:0" window.
void checkTimerExpiry() {
  if (brewTimerCheckExpiry(brewTimer, millis())) {
    buzzerBeep();
    syslog.log(LOG_INFO, "Brew timer expired");
  }
}

// Sensor state
int numberOfDevices;
DeviceAddress tempDeviceAddress;
DeviceAddress sensorAddresses[SENSOR_MAXIMUM];
float temperatures[SENSOR_MAXIMUM] = { NAN, NAN, NAN, NAN, NAN };
unsigned long lastSensorReadTime = 0;

// Sensor calibration — slope/offset computed once at startup from two-point config (see config_example.h)
float dsCalSlope[SENSOR_MAXIMUM];
float dsCalOffset[SENSOR_MAXIMUM];
float pt100xCalSlope, pt100xCalOffset;
float bme680CalSlope, bme680CalOffset;

// ─── Induction cooker class ───────────────────────────────────────────────────

class induction {
  static const uint8_t PWR_STEPS[6];

  unsigned long timeTurnedoff;
  unsigned long lastInterrupt;
  bool inputStarted = false;
  unsigned char inputCurrent = 0;
  unsigned char inputBuffer[33];
  volatile uint8_t newError = 0;
  long powerSampletime = 20000;
  unsigned long powerLast;
  long powerHigh = powerSampletime;
  long powerLow = 0;

  int CMD[6][33] = {
    { 1, 0, 1, 0, 0, 0, 0, 0, 0, 0, 0, 0, 0, 0, 0, 0, 0, 0, 0, 0, 0, 0, 0, 0, 0, 0, 1, 0, 0, 0, 0, 0, 0 },  // Off
    { 1, 0, 0, 1, 0, 0, 0, 0, 0, 1, 0, 0, 0, 0, 0, 0, 0, 0, 0, 0, 0, 0, 0, 0, 0, 1, 0, 1, 0, 0, 0, 0, 0 },  // P1
    { 1, 0, 0, 1, 0, 0, 0, 0, 0, 0, 1, 0, 0, 0, 0, 0, 0, 0, 0, 0, 0, 0, 0, 0, 0, 0, 1, 1, 0, 0, 0, 0, 0 },  // P2
    { 1, 0, 0, 1, 0, 0, 0, 0, 0, 1, 1, 0, 0, 0, 0, 0, 0, 0, 0, 0, 0, 0, 0, 0, 0, 1, 1, 1, 0, 0, 0, 0, 0 },  // P3
    { 1, 0, 0, 1, 0, 0, 0, 0, 0, 0, 0, 1, 0, 0, 0, 0, 0, 0, 0, 0, 0, 0, 0, 0, 0, 0, 0, 0, 1, 0, 0, 0, 0 },  // P4
    { 1, 0, 0, 1, 0, 0, 0, 0, 0, 1, 0, 1, 0, 0, 0, 0, 0, 0, 0, 0, 0, 0, 0, 0, 0, 1, 0, 0, 1, 0, 0, 0, 0 }   // P5
  };

public:
  unsigned char PIN_WHITE     = INDUCTION_PIN_WHITE;
  unsigned char PIN_YELLOW    = INDUCTION_PIN_YELLOW;
  unsigned char PIN_INTERRUPT = INDUCTION_PIN_BLUE;
  int power    = 0;
  int newPower = 0;
  unsigned char CMD_CUR  = 0;
  boolean isRelayon      = false;
  boolean isInduon       = false;
  long delayAfteroff     = INDUCTION_FAN_DELAY;

  induction() {
    for (int i = 0; i < 33; i++)
      for (int j = 0; j < 6; j++)
        CMD[j][i] = (CMD[j][i] == 1) ? SIGNAL_HIGH : SIGNAL_LOW;
  }

  void millis2wait(const int &value) { delay(value); }

  void Update() {
    updatePower();
    isRelayon = updateRelay();
    if (isInduon && power > 0) {
      if (deadlineReached(millis(), powerLast + powerSampletime)) powerLast = millis();
      if (deadlineReached(millis(), powerLast + powerHigh)) {
        sendCommand(CMD[CMD_CUR - 1]);
      } else {
        sendCommand(CMD[CMD_CUR]);
      }
    } else if (isRelayon) {
      sendCommand(CMD[0]);
    }
  }

  bool updateRelay() {
    if (isInduon && !isRelayon) { digitalWrite(PIN_WHITE, HIGH); return true; }
    if (!isInduon && isRelayon) {
      if (deadlineReached(millis(), timeTurnedoff + delayAfteroff)) { digitalWrite(PIN_WHITE, LOW); return false; }
    }
    return isRelayon;
  }

  void updatePower() {
    if (power == newPower) return;
    newPower = min(100, max(0, newPower));
    power = newPower;
    timeTurnedoff = 0;
    isInduon = true;

    if (power == 0) {
      CMD_CUR = 0;
      timeTurnedoff = millis();
      isInduon = false;
      powerLow = powerHigh = 0;
      return;
    }
    PowerLevel lvl = computePowerLevel(power, powerSampletime, PWR_STEPS);
    CMD_CUR   = lvl.cmdIndex;
    powerHigh = lvl.powerHigh;
    powerLow  = lvl.powerLow;
  }

  void sendCommand(const int command[33]) {
    digitalWrite(PIN_YELLOW, HIGH); millis2wait(SIGNAL_START);
    digitalWrite(PIN_YELLOW, LOW);  millis2wait(SIGNAL_WAIT);
    for (int i = 0; i < 33; i++) {
      digitalWrite(PIN_YELLOW, HIGH); delayMicroseconds(command[i]);
      digitalWrite(PIN_YELLOW, LOW);  delayMicroseconds(SIGNAL_LOW);
    }
  }

  // IRAM_ATTR: called from readInputWrap(), an ISR — must stay resident in IRAM so it's
  // safe to call while flash cache is disabled (e.g. during OTA writes or NVS commits).
  void IRAM_ATTR readInput() {
    bool ishigh = digitalRead(PIN_INTERRUPT);
    unsigned long newInterrupt = micros();
    long signalTime = newInterrupt - lastInterrupt;
    PulseType pulse = classifyPulse(signalTime);
    if (pulse == PulseType::NOISE) return;
    if (ishigh) { lastInterrupt = newInterrupt; return; }
    if (!inputStarted) {
      if (pulse == PulseType::START) { inputStarted = true; inputCurrent = 0; }
    } else if (inputCurrent < 33) {
      if (pulse == PulseType::BIT_ONE)  inputBuffer[inputCurrent++] = 1;
      if (pulse == PulseType::BIT_ZERO) inputBuffer[inputCurrent++] = 0;
    } else {
      // Frame complete
      newError = decodeErrorCode(inputBuffer);
      inputCurrent = 0;
      inputStarted = false;
    }
  }

  uint8_t getError() const { return newError; }
  void clearError()         { newError = 0; }
};

const uint8_t induction::PWR_STEPS[6] = { 0, 20, 40, 60, 80, 100 };

induction inductionCooker;
uint8_t inductionLastError = 0;

void ARDUINO_ISR_ATTR readInputWrap() {
  inductionCooker.readInput();
}

// ─── Safety ───────────────────────────────────────────────────────────────────

bool isSensorHealthy() {
  return sensorIsHealthy(millis(), lastSensorReadTime, SENSOR_STALE_TIMEOUT_MS, numberOfDevices);
}

// Cut induction power and disable PID. Called on any safety event.
void safetyShutdown(const char *reason) {
  inductionCooker.newPower = 0;
  inductionCooker.Update();
  setLED(0);
  PID_state = false;
  ledEmergencyBlink();
  buzzerAlarm();
  char msg[80];
  snprintf(msg, sizeof(msg), "SAFETY SHUTDOWN: %s", reason);
  syslog.log(LOG_CRIT, msg);
#if SERIAL_ENABLE
  Serial.println(msg);
#endif
}

// ─── Induction timer callback ─────────────────────────────────────────────────

void handleInduction() {
  inductionCooker.Update();
  setLED(inductionCooker.power);
}

// ─── Display ──────────────────────────────────────────────────────────────────

void setup_display(Adafruit_SSD1306 &disp, unsigned int address) {
  if (!disp.begin(SSD1306_SWITCHCAPVCC, address)) {
#if SERIAL_ENABLE
    Serial.println(F("Display allocation failed"));
#endif
  }
  disp.clearDisplay();
  disp.setTextColor(WHITE);
  disp.setFont(&FreeSans24pt7b);
  disp.setCursor(29, 46);
  disp.println("OK");
  disp.display();
}
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
void loop() {
  esp_task_wdt_reset();

  handleButton(analogRead(BUTTON_PIN));

  ArduinoOTA.handle();
  webServer.handleClient();

  mqttClient.loop();
  if (!mqttClient.connected()) reconnect_mqtt();

  timerTempRead.tick();
  timerTempStatus.tick();
  timerInductionStatus.tick();
  timerDisplayUpdate.tick();

  checkTimerExpiry();

  // Safety: sensor staleness — fires whenever the cooker is on, regardless of mode
  if (inductionCooker.isInduon && !isSensorHealthy()) {
    char buf[48];
    snprintf(buf, sizeof(buf), "primary sensor stale >%lus", SENSOR_STALE_TIMEOUT_MS / 1000UL);
    safetyShutdown(buf);
  }

  // Safety: thermal runaway — standalone only; slave mode relies on the cooker's own E3 protection
  if (deviceMode == MODE_STANDALONE && PID_state
      && isThermalRunaway(PID_Input, PID_Setpoint, (double)PID_SAFETY_OVERSHOOT)) {
    char buf[48];
    snprintf(buf, sizeof(buf), "thermal runaway T=%.1f setpoint=%.1f", PID_Input, PID_Setpoint);
    safetyShutdown(buf);
  }

  // Induction error: read status frame from cooker RX interrupt
  {
    uint8_t err = inductionCooker.getError();
    if (err != inductionLastError) {
      inductionLastError = err;
      char msg[56];
      if (err == 0) {
        syslog.log(LOG_INFO, "Induction: error cleared");
      } else {
        snprintf(msg, sizeof(msg), "Induction error: %s (code %u)", inductionErrorString(err), err);
        syslog.log(LOG_WARNING, msg);
        if (err == 4 || err == 5) safetyShutdown("induction E3 overheat");
        if (err == 9)             safetyShutdown("induction E7 low voltage");
        if (err == 10)            safetyShutdown("induction E8 high voltage");
      }
    }
  }

  // Relay timer — auto-off when duration expires
  if (relayTimerEndMs > 0 && deadlineReached(millis(), relayTimerEndMs)) {
    setRelay(false);
    relayTimerEndMs = 0;
    if (mqttClient.connected()) relay_write_mqtt();
  }

  // GPIO5 timer — auto-off when duration expires
  if (gpio5TimerEndMs > 0 && deadlineReached(millis(), gpio5TimerEndMs)) {
    setGPIO5(false);
    gpio5TimerEndMs = 0;
    if (mqttClient.connected()) gpio5_write_mqtt();
  }

  // PID control — standalone mode only
  if (deviceMode == MODE_STANDALONE && PID_state) {
    if (pidTuningsDirty) {
      myPID.SetTunings(PID_P, PID_I, PID_D);
      pidTuningsDirty = false;
    }
    myPID.Compute();
    inductionCooker.newPower = constrain((int)Output, 0, powerCap);
    inductionCooker.Update();
    setLED(inductionCooker.power);
  }
}

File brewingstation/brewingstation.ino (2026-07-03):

// Project for an automated beer brewing station with the purpose to automatically hold a certain temperature in a beer kettle based on temperature sensors and by controlling an induction cooker
// Remains compatible to CraftBeerPi 3 and 4
// Induction Cooker Code based on the work of Innuendo: https://github.com/InnuendoPi/MQTTDevice2
// Used devices: DS18B20 within metal/silicon tubes, GGM IDS2 induction cooker (via serial connection), SSD1306 OLED displays
// Michael Morscher, April 2023
// Tested on Arduino IDE 2.0.4 / VSCode
// Board: DOIT ESP32 DEVKIT V1
#include <WiFi.h>
#include <WiFiUdp.h>
#include <Wire.h>
#include <SPI.h>

// Additional used libraries
#include <ArduinoOTA.h>
#include <ESPmDNS.h>
#include <PubSubClient.h>
#include <ArduinoJson.h>
#include <Syslog.h>
#include "timer.h"
#include "timerManager.h"
#include <OneWire.h>
#include <DallasTemperature.h>
#include <Adafruit_Sensor.h>
#include <Adafruit_MAX31865.h>
#include <Adafruit_BME280.h>
#include <PID_v1.h>
#include <Adafruit_GFX.h>
#include <Adafruit_SSD1306.h>
#include <Fonts/FreeSans9pt7b.h>
#include <Fonts/FreeSans18pt7b.h>
#include <Fonts/FreeSans24pt7b.h>
#include "config.h"

#define VERSION 1.13

// Feature Toggles
#define SERIAL_ENABLE false
#define MQTT_ENABLE true
#define PUBLISH_ENABLE true

#define SENSOR_MAXIMUM 5  // Total amount of possible sensors
#define TEMPERATURE_MQTT_STATUS "temperature"

// Sensors & Displays
OneWire oneWire(SENSOR_BUS_PIN);
DallasTemperature sensorlist(&oneWire);
Adafruit_MAX31865 pt100x = Adafruit_MAX31865(SENSOR_PT100X_CS_PIN, SENSOR_PT100X_DI_PIN, SENSOR_PT100X_DO_PIN, SENSOR_PT100X_CLK_PIN);  // Software SPI
bool pt100x_found = false;
Adafruit_BME280 bme280 = Adafruit_BME280(SENSOR_BME280_CS_PIN, SENSOR_BME280_DI_PIN, SENSOR_BME280_DO_PIN, SENSOR_BME280_CLK_PIN);  // Software SPI
bool bme280_found = false;
Adafruit_SSD1306 display(DISPLAY_SCREEN_WIDTH, DISPLAY_SCREEN_HEIGHT, &Wire, DISPLAY_OLED_RESET);
Adafruit_SSD1306 display2(DISPLAY_SCREEN_WIDTH, DISPLAY_SCREEN_HEIGHT, &Wire, DISPLAY_OLED_RESET);
// Wifi
const uint8_t bitmap26[] = { 0x00, 0x00, 0x00, 0x00, 0x00, 0x00, 0x00, 0x00, 0x00, 0x00, 0x00, 0x00, 0x01, 0xff, 0x80, 0x07, 0xff, 0xe0, 0x1f, 0x81, 0xf8, 0x7c, 0x00, 0x3e, 0xf0, 0x00, 0x0f, 0xe0, 0xff, 0x07, 0x03, 0xff, 0xc0, 0x0f, 0xe7, 0xf0, 0x0f, 0x00, 0xf0, 0x08, 0x00, 0x10, 0x00, 0x7e, 0x00, 0x00, 0xff, 0x00, 0x00, 0xe7, 0x00, 0x00, 0x00, 0x00, 0x00, 0x00, 0x00, 0x00, 0x18, 0x00, 0x00, 0x18, 0x00, 0x00, 0x00, 0x00, 0x00, 0x00, 0x00, 0x00, 0x00, 0x00 };
// Incoming MQTT message
const uint8_t bitmap27[] = { 0x00, 0x00, 0x00, 0x00, 0x00, 0x00, 0x00, 0x18, 0x00, 0x00, 0x18, 0x00, 0x00, 0x18, 0x00, 0x00, 0x18, 0x00, 0x00, 0x18, 0x00, 0x00, 0x18, 0x00, 0x00, 0x18, 0x00, 0x03, 0x18, 0xc0, 0x03, 0x99, 0x80, 0x01, 0xdb, 0x80, 0x00, 0xff, 0x00, 0x00, 0x7e, 0x00, 0x30, 0x3c, 0x0c, 0x30, 0x18, 0x0c, 0x30, 0x00, 0x0c, 0x30, 0x00, 0x0c, 0x30, 0x00, 0x0c, 0x38, 0x00, 0x1c, 0x3f, 0xff, 0xfc, 0x1f, 0xff, 0xf8, 0x00, 0x00, 0x00, 0x00, 0x00, 0x00 };
bool display_toggle = true;

// Button resistor ladder
#define BUTTON_PIN 34
// Define the resistor values for each button
const int R1 = 10000;
const int R2 = 20000;
const int R3 = 30000;
const int R4 = 40000;
const int R5 = 50000;
const int R6 = 60000;

// Induction Cooker
const int SIGNAL_HIGH = 5120;
const int SIGNAL_HIGH_TOL = 1500;
const int SIGNAL_LOW = 1280;
const int SIGNAL_LOW_TOL = 500;
const int SIGNAL_START = 25;
const int SIGNAL_START_TOL = 10;
const int SIGNAL_WAIT = 10;
const int SIGNAL_WAIT_TOL = 5;
unsigned char PWR_STEPS[6] = { 0, 20, 40, 60, 80, 100 };  // Power steps in percentage between states
unsigned char PWR_LEDS[6] = { INDUCTION_LED_0_PIN, INDUCTION_LED_20_PIN, INDUCTION_LED_40_PIN, INDUCTION_LED_60_PIN, INDUCTION_LED_80_PIN, INDUCTION_LED_100_PIN };
String errorMessages[10] = { "E0", "E1", "E2", "E3", "E4", "E5", "E6", "E7", "E8", "EC" };

// PID controller
#define PID_MQTT_TOPIC "pid"
double PID_Setpoint;
double PID_Input;
double Output;
double Output_Limit_Max = 100;
double Output_Limit_Min = 0;
double PID_P = 45.27;
double PID_I = 0.2371;
double PID_D = 7.2;
bool PID_state = false;
PID myPID(&PID_Input, &Output, &PID_Setpoint, PID_P, PID_I, PID_D, P_ON_M, DIRECT);  //P_ON_M specifies that Proportional on Measurement be used
                                                                                     //P_ON_E (Proportional on Error) is the default behavior

// Network settings
const char *ssid = SSID_NAME;
const char *password = SSID_PASSWORD;
const char *hostname = HOSTNAME;
WiFiClient wifiClient;
WiFiUDP udpClient;
PubSubClient mqttClient(wifiClient);
Syslog syslog(udpClient, SYSLOG_SERVER, SYSLOG_PORT, hostname, SYSLOG_APP_NAME, LOG_KERN);
bool message_received = false;

// Subscribe-side topics for mqttCallback() — built from MQTT_ROOT_PATH/MQTT_DEVICE once at
// startup (see setup_topics()) instead of hardcoding the root/device names in every comparison.
char TOPIC_HEATER_POWER[64];
char TOPIC_PID_ROOT[64];
char TOPIC_PID_CONTROL[64];
char TOPIC_PID_RESET[64];
char TOPIC_PID_P[64];
char TOPIC_PID_I[64];
char TOPIC_PID_D[64];
char TOPIC_PID_TARGET[64];

void setup_topics() {
  snprintf(TOPIC_HEATER_POWER, sizeof(TOPIC_HEATER_POWER), "%s/%s/%s", MQTT_ROOT_PATH, MQTT_DEVICE, INDUCTION_MQTT_COMMANDS);
  snprintf(TOPIC_PID_ROOT,     sizeof(TOPIC_PID_ROOT),     "%s/%s/%s", MQTT_ROOT_PATH, MQTT_DEVICE, PID_MQTT_TOPIC);
  snprintf(TOPIC_PID_CONTROL,  sizeof(TOPIC_PID_CONTROL),  "%s/%s/%s/control", MQTT_ROOT_PATH, MQTT_DEVICE, PID_MQTT_TOPIC);
  snprintf(TOPIC_PID_RESET,    sizeof(TOPIC_PID_RESET),    "%s/%s/%s/reset",   MQTT_ROOT_PATH, MQTT_DEVICE, PID_MQTT_TOPIC);
  snprintf(TOPIC_PID_P,        sizeof(TOPIC_PID_P),        "%s/%s/%s/p",       MQTT_ROOT_PATH, MQTT_DEVICE, PID_MQTT_TOPIC);
  snprintf(TOPIC_PID_I,        sizeof(TOPIC_PID_I),        "%s/%s/%s/i",       MQTT_ROOT_PATH, MQTT_DEVICE, PID_MQTT_TOPIC);
  snprintf(TOPIC_PID_D,        sizeof(TOPIC_PID_D),        "%s/%s/%s/d",       MQTT_ROOT_PATH, MQTT_DEVICE, PID_MQTT_TOPIC);
  snprintf(TOPIC_PID_TARGET,   sizeof(TOPIC_PID_TARGET),   "%s/%s/%s/target", MQTT_ROOT_PATH, MQTT_DEVICE, PID_MQTT_TOPIC);
}

// Timer
Timer timerTempStatus;
Timer timerTempRead;
Timer timerInductionStatus;
Timer timerDisplayUpdate;

// Temperature sensor variables
int numberOfDevices;                           // Number of temperature devices found
DeviceAddress tempDeviceAddress;               // Temporary storage for a devices address
DeviceAddress sensorAdresses[SENSOR_MAXIMUM];  // List of all found sensor addresses
float temperatures[SENSOR_MAXIMUM];
float temperature_combined;
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

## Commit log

2023-04-01 Initial commit of brewingstation V1
    [brewingstation.fzz]
2026-07-03 Move V1 files into brewingstation/ subfolder
    Reorganizing to accommodate multiple brewing station versions
    (brewingstation, brewingstation2, brewingstation3, brewingstation_old)
    in a single repo, mirroring the layout from esp8266projects.
    [brewingstation.fzz]
2026-07-03 Add brewingstation2, brewingstation3, and brewingstation_old
    Copied as-is from esp8266projects (were untracked there). No prior
    git history exists for these folders since they were never committed
    in the source repo.
    [.step, brewingstation.fzz, brewingstation2.fzz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]
2026-07-03 Track kicad/.history as regular files, not a nested repo
    The .history folder had its own embedded .git (from a local-history
    tool), which git recorded as a submodule gitlink instead of real
    content. Removed the nested repo so the backup snapshots are tracked
    normally.
2026-07-03 Remove brewingstation_old, superseded by brewingstation V1
    It had no README/config split and offered nothing brewingstation
    doesn't already cover.
    [brewingstation.fzz]
2026-07-03 Mark brewingstation3 as work in progress
    Not yet soldered/assembled, untested end-to-end, and the case hasn't
    been printed.
2026-07-03 brewingstation3: implement buzzer firmware
    Add LEDC-based tone driver (setup_buzzer/buzzerBeep/buzzerAlarm) and
    wire it into brew-timer expiry and safetyShutdown(), closing the
    buzzer item on the backlog. Also reorder safetyShutdown() to cut
    induction power before the blocking LED/buzzer alarm plays, instead
    of after.
    [config_example.h, main.cpp]
2026-07-03 Add PlatformIO support to brewingstation and brewingstation2
    Both keep their .ino as the Arduino IDE entry point (src_dir = .);
    PlatformIO now builds them too via the same pioarduino toolchain
    workaround already used by brewingstation3. Verified all three build
    successfully (esp32doit-devkit-v1 / esp32c6).
2026-07-03 brewingstation3: add two-point sensor calibration
    Adds runtime-computed linear calibration (slope + offset from two
    reference points) for DS18B20, MAX31865, and BME680 readings,
    replacing the previous fixed BME680-only offset constant.
    [config_example.h, main.cpp]
2026-07-03 Add GitHub Actions CI to build brewingstation3
    Builds both esp32c6 and esp32c6_debug PlatformIO environments on
    push/PR touching brewingstation3/, using config_example.h as the
    local config.h stand-in since real secrets are gitignored. Verified
    locally that config_example.h alone compiles cleanly for both envs.
2026-07-03 brewingstation3: add native unit tests for calibration/button/error logic
    Extract computeCalibration(), getButtonBucket(), and
    inductionErrorString() into include/pure_logic.h, a hardware-free
    header, and add a Unity test suite (test/test_pure_logic) that runs
    on the host via `pio test -e native` (no ESP32 toolchain or device
    needed). Wire it into CI as a separate job. Verified locally under
    WSL: 9/9 tests pass, and the esp32c6 build still compiles cleanly.
    [main.cpp]
2026-07-03 Add badges, LICENSE, and testing/workspace docs to root README
    Add CI, license, PlatformIO, and framework badges; add MIT LICENSE;
    document the native test suite and the multi-root VS Code workspace.
2026-07-03 Bring brewingstation/brewingstation2 docs and tooling up to v3's standard
    - Rewrite brewingstation/README.md: proper headers, hardware/MQTT
    tables, build instructions for both Arduino IDE and PlatformIO,
    reorganized known-gaps section (previously a flat unstructured doc).
    - Fix brewingstation2/README.md's dead link to a nonexistent
    ../CONTEXT.md; add matching Build & Flash section.
    - Track the PlatformIO/VS Code scaffolding (.gitignore,
    .vscode/extensions.json) that v3 already commits, extending the same
    convention to both older generations. c_cpp_properties.json and
    launch.json stay gitignored (machine-generated, not portable).
2026-07-03 Fix hardcoded "cave/brewery" MQTT topics in brewingstation/2 mqttCallback
    The subscribe side already built topics from MQTT_ROOT_PATH/MQTT_DEVICE,
    but mqttCallback() compared incoming topics against literal
    "cave/brewery/..." strings. Changing those config values away from the
    defaults silently broke every induction/PID command. Add setup_topics()
    to precompute the comparison strings once at startup, matching the
    pattern brewingstation3 already uses.
    Also flagged (not fixed): the trailing debug block compares with
    `== 1` instead of `== 0`/`!= 0`, so it never actually fires; left
    as pre-existing behavior since it's unrelated to the topic bug.
    Verified both esp32doit-devkit-v1 builds still c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
    [brewingstation.ino]
2026-07-03 Fix debug-block strcmp bug in brewingstation/2 mqttCallback
    Changed == 1 to == 0 so the bare pid-topic debug log actually fires
    instead of being permanently dead code.
    [brewingstation.ino]
2026-07-03 Merge brewingstation2 into brewingstation as a hardware variant
    brewingstation2 was a byte-for-byte copy of brewingstation's firmware
    with a different PCB instead of a breadboard — every fix had to be
    applied twice by hand (as just happened with the MQTT topic bug).
    Collapse it into a single project with one canonical .ino/config, and
    move each variant's Fritzing/gerber/schematic files into
    hardware/breadboard/ and hardware/pcb/ subfolders.
    Update brewingstation/README.md to document both hardware variants in
    one place (merging both former READMEs), and fix references to the
    now-removed brewingstation2/ folder in the root README and
    brewingstation3/CLAUDE.md.
    Verified brewingstation stil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
    [brewingstation.fzz, brewingstation2.fzz, brewingstation2_updated.fzz]
2026-07-03 Add tag-triggered release workflow for brewingstation (V1)
    On pushing a vX.Y.Z tag, builds the firmware and publishes a GitHub
    Release with: individual + merged flashable binaries, SHA256
    checksums, zipped hardware design files per variant (breadboard/PCB),
    and flashing instructions in the release notes. Dry-ran the asset
    staging script locally (WSL) against a real build — all 6 assets and
    checksums generated correctly.
2026-07-03 brewingstation3: prepare versioning and release workflow
    - Bump VERSION to "3.0.0-alpha.1" (SemVer pre-1.0 track, signals
    unverified hardware) from the old bare "3.0".
    - Add tag-triggered release workflow: gates on the native test suite,
    then builds firmware and publishes a GitHub pre-release with
    individual + merged binaries, a KiCad design snapshot (excluding
    editor backup/history cruft), the case source, and checksums.
    - Tags use a plain "3.*" pattern (no "v" prefix) to avoid colliding
    with brewingstation (V1)'s existing vX.Y.Z tags.
    - Document the convention in brewingstation3/README.md.
    Dry-ran the asset staging script locally (WSL) against a real build —
    all 6 assets and c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
    [main.cpp]
2026-07-03 brewingstation3: remove tracked KiCad tooling backups
    .mcp-backups/ (20 timestamped PCB snapshots), _restore_backup_*/,
    and a stale kicad.zip were tracked in git despite being generated
    noise from KiCad MCP tooling, not canonical source. Untrack, delete
    from disk, and gitignore them so they don't come back. ~4.8MB removed
    from working tree; canonical .kicad_sch/.kicad_pcb/.kicad_pro files
    are untouched.
    [brewingstation3.kicad_pcb, brewingstation3.kicad_sch]
2026-07-07 brewingstation3: fix 8 bugs from code review
    Safety/correctness:
    - Fix OOB write in induction RX ISR: inputBuffer[33] was written at
    index 33 (inputCurrent < 34), one past the end, corrupting the
    adjacent newError field and potentially masking real E3/E7/E8 faults.
    - Fix sensor-staleness tracking only updating lastSensorReadTime for
    DS18B20 reads — if the PID sensor is the PT100X or BME680, the
    staleness safety check would spuriously fire ~30s after boot. Also
    stop overwriting temperatures[] with the PT100X "disconnected"
    sentinel, which would have silently defeated the same check.
    - Validate MQTT payloads on induction/cap, pid/setpoint, pid/p, pid/i,
    pid/d before applying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
    [main.cpp]
2026-07-07 brewingstation3: fix judgment-call issues from code review
    - Replace fragile PT100X "no sensor" detection (exact float equality
    against an empirically observed sentinel) with a threshold check
    (PT100X_FAULT_THRESHOLD), robust across library versions/compilers.
    - Move brew-timer expiry detection out of display_update() into
    checkTimerExpiry(), called every loop() iteration instead of being a
    side effect of the display refresh cadence — timer_write_mqtt() can
    no longer report a stale "running:1, remaining:0" window between
    display ticks.
    - Narrow the pid/# MQTT subscription to pid/+: "#" also matches the
    bare pid topic, which is where this device publishes its own status
    ever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
    [main.cpp]
2026-07-07 brewingstation3: add OTA validation to post-assembly backlog
    New "Post-assembly validation" section for work that needs the
    physical board rather than just firmware/schematic — starting with
    verifying the ArduinoOTA workflow end-to-end once soldered, including
    replacing the OTA_PASSWORD placeholder with a real password.
2026-07-07 brewingstation3: expand post-assembly validation into full bring-up checklist
    10-stage checklist covering power-on/connectivity, sensor detection +
    two-point calibration, induction cooker verification, button/LED
    calibration, PID re-tuning, safety system tests, buzzer, timer/MQTT
    control, case fit, and a soak test. Ordered so each stage assumes the
    previous one passed. Several items are explicit regression checks for
    bugs fixed this session (power cap clamping, pid/reset, pid/enable in
    slave mode, timer expiry).
2026-07-07 brewingstation3: bump version to 3.0.0-alpha.2
    Rolls the accumulated bug-fix/judgment-call/checklist work into a new
    pre-release, to test the new CHANGELOG-sourced release notes workflow.
    [main.cpp]
2026-07-07 brewingstation3: extract more pure logic for native unit testing
    Pulls the remaining review-flagged, hardware-independent logic out of
    main.cpp into pure_logic.h so it's testable under `pio test -e native`:
    - computePowerLevel(): induction power (0-100) -> PWM level/duty-cycle
    math, previously inline in induction::updatePower().
    - classifyPulse()/decodeErrorCode(): RX pulse classification and frame
    decoding, previously inline in induction::readInput() (where bug #1,
    the OOB write, originally lived).
    - BrewTimerState + brewTimer*(): the brew timer as an explicit state
    machine taking an injected `now`, replacing five loose globals and
    the logic scattered across timerRemainingMs()/ch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
    [main.cpp]
2026-07-07 brewingstation3: add WiFiManager captive-portal provisioning
    Replaces the hardcoded WiFi.begin()+reboot-on-fail connect with WiFiManager,
    which opens a captive portal on first boot/failed connect or when a panel
    button is held ~2s at power-on. The same portal now also provisions the MQTT
    broker address, MQTT topic prefix, and OTA password at runtime (persisted to
    /netconfig.json), closing out both the "WiFi setup via captive portal" and
    "configurable MQTT topic prefix" backlog items in one pass.
    Also switches the partition table to default_8MB.csv: the board is the N8
    (8MB flash) module but was left on PlatformIO's stock 4MB scheme, leaving
    only ~1.25MB/91%-full app partitions before this w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
    [config_example.h, main.cpp]
2026-07-07 brewingstation3: dedupe device-mode label, add pre-release badge
    Extracts deviceModeName() into pure_logic.h to replace a "slave"/
    "standalone" ternary duplicated across 5 call sites, and adds
    isPrereleaseVersion() to flag alpha/beta builds with a warning badge
    in the web dashboard's nav bar. 5 new native tests (50 total).
    [main.cpp]
2026-07-07 brewingstation3: add MQTT Last Will/availability topic
    Registers a retained LWT ("offline") and a retained "online" publish
    on connect/reconnect, so any MQTT subscriber can detect the device
    dropping off the network instead of inferring it from a stale status
    topic. Also a prerequisite for a possible future Home Assistant
    MQTT auto-discovery integration.
